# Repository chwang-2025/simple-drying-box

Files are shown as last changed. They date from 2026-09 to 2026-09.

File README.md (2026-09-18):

# 简易干燥盒

基于 STC8H1K17T 的小型加热干燥盒项目，包含外壳模型、电路资料和固件。项目仍处于原型验证阶段；现有固件针对**第一版实装 PCB**，请先核对接线并完成无负载测试，再连接加热片。

## 项目内容

| 路径 | 内容 |
| --- | --- |
| [`firmware/oled_test/`](firmware/oled_test/) | PlatformIO 固件、烧录辅助脚本和第一版 PCB 接线说明 |
| [`原理图/`](原理图/) | 原理图 PDF 与物料清单 |
| [`PCB/`](PCB/) | PCB 截图 |
| `*.SLDPRT`、`*.SLDASM`、`*.step` | 结构设计与 PCB 三维文件 |
| [`干燥盒子项目_简易.md`](干燥盒子项目_简易.md) | 原始功能规划，部分内容尚未在现有版本实现 |

## 当前固件

- OLED 显示温度和运行状态，按键设定目标温度（30～80 ℃）及倒计时（5～180 分钟）。
- 加热输出采用 5 秒周期的时间比例控制；温度远低于设定值时全功率输出，接近设定值时使用待实测整定的 PID 参数。
- NTC 读数异常、温度达到 85 ℃、倒计时结束或人工停止时关闭加热；故障锁定后需检查硬件并重新上电。
- **这一版不接风扇。**原风扇接口 H2 改作加热输出，H3 不可接加热片。第一版 PCB 的原理图库引脚映射与实装芯片不一致，详见[固件接线和验收说明](firmware/oled_test/README.md)。

## 编译

安装 PlatformIO 后，在 `firmware/oled_test` 目录执行：

```sh
platformio run
```

生成文件位于 `.pio/build/oled_test/firmware.hex`。编译通过仅说明固件可构建，不代表温控精度或实物安全已验证。

## 使用前检查

1. 核对实装芯片型号、H2 接口极性、加热片额定电压和功率，以及电源、驱动器件和 PCB 走线的承载能力。
2. **先断开加热片**，按[固件说明](firmware/oled_test/README.md)验证待机、运行、停止和 NTC 故障状态下的驱动电压。
3. 为加热片设置独立于单片机的软件之外的温度保护，并检查外壳材料的耐热性。
4. 记录实际升温和超调曲线，再整定 PID 参数；不要将当前参数视为已经验证的恒温性能。

## 说明

原始功能规划提到风扇排湿等目标；当前第一版 PCB 固件的实际接线和功能以 [`firmware/oled_test/README.md`](firmware/oled_test/README.md) 为准。仓库不包含本地编译结果、Python 环境和临时文件。

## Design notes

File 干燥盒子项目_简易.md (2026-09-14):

# 简易干燥盒 —— 功能总结报告

## 一、项目定位

便携式实验室**恒温干燥盒（简易版）**，用于小体积样品（如电子元件、试剂、小型器件）的加热干燥与防潮保存。相比智能版（TEC 能量回收 + 内胆识别），本版砍掉复杂功能，主打**低成本（¥15–20）、结构简单、易维护**。

## 二、核心功能

| 功能模块 | 实现方式 | 说明 |
|---|---|---|
| **恒温加热** | PTC 加热片 + PWM 控制 | 5V/5W PTC 加热片，通过 PWM 调节加热功率实现温度闭环 |
| **温度监测** | NTC 热敏电阻（100k B=3950）+ ADC | 分压采样，实时读取腔内温度，作为控温反馈 |
| **气流循环/排湿** | 5V 微型风扇 + PWM | 加速腔内空气流动，带走湿气、均匀温度 |
| **状态显示** | 0.96" OLED（SSD1306 I²C） | 显示当前温度、目标温度、工作模式 |
| **用户交互** | 3 个轻触按键 | UP / MODE / DOWN，调温与模式切换 |
| **声光提示** | 无源蜂鸣器 + 红色 LED | 按键反馈、到温/超温报警、工作状态指示 |
| **供电** | USB-C 5V 输入 | AMS1117 转 3.3V 供 MCU，TVS+肖特基防反接/防浪涌 |
| **调试通信** | CH340N（USB 转 UART） | 串口烧录与上位机调试 |

## 三、控制逻辑（预期）

1. 用户通过按键设定**目标温度**（如 40°C / 50°C / 60°C）
2. MCU 读取 NTC 温度 → 与目标比较 → 输出 PWM 驱动 PTC 加热
3. 温度接近目标时降低占空比，实现 PID 或分段温控
4. 超温时停止加热并蜂鸣报警；风扇按需运行辅助排湿/降温
5. OLED 实时刷新温度与状态，LED 指示工作/报警

## 四、硬件架构概览

- **主控**：STC8H1K17T（SOP-20，8051 内核，自带 PWM/ADC）
- **电源链**：USB-C → SS34 反接保护 → TVS 浪涌 → AMS1117-3.3
- **驱动**：AO3400 N-MOSFET ×2（PTC、风扇）+ S8050（蜂鸣器）
- **板框**：60mm × 45mm，立创EDA

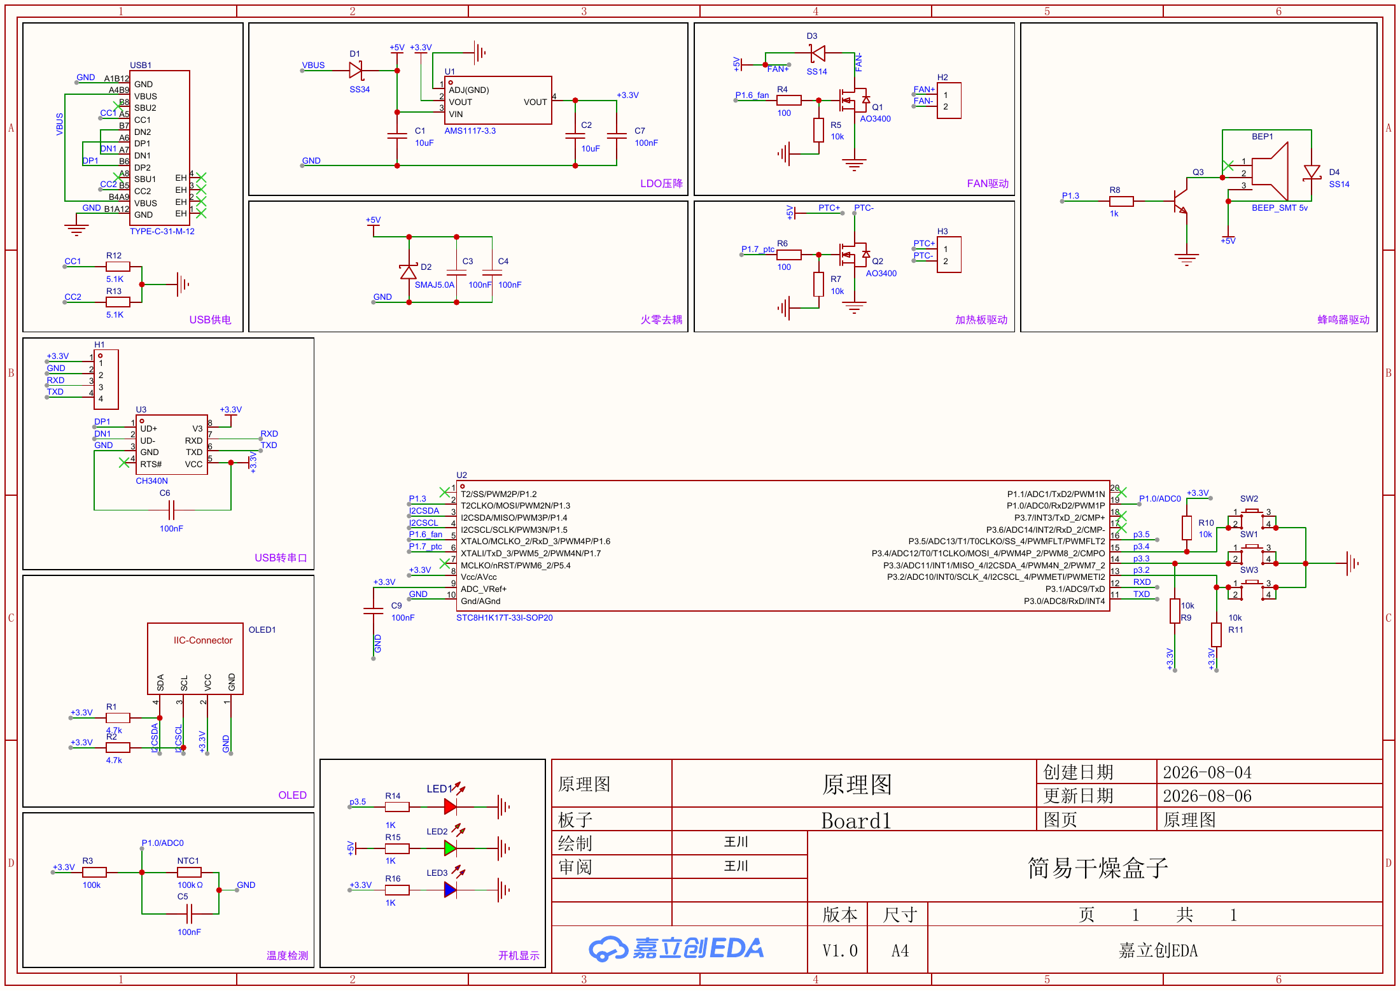
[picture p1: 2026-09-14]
schematic-review.png

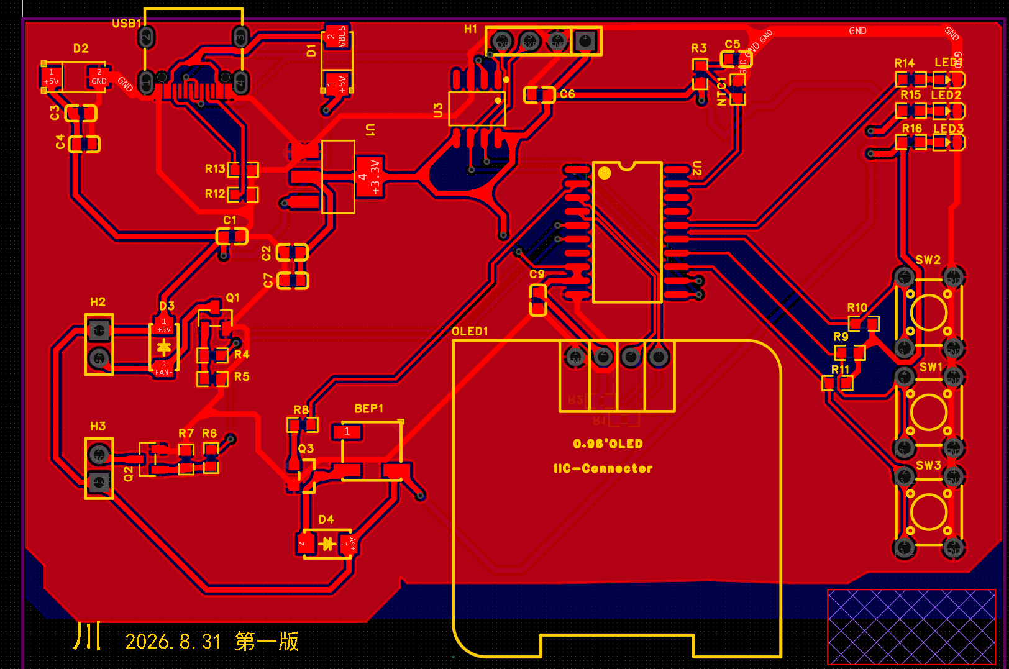
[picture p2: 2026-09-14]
PCB/Screenshot 2026-09-11 123319.png

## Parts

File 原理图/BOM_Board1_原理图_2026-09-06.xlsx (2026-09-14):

No. | Comment | Designator | Footprint | Value | Manufacturer Part | Manufacturer | Supplier Part | Supplier | Category | Device | 匹配状态 | 对方 BOM 对应位号 | 匹配依据
4 | SS34 | D1 | SMA_L4.3-W2.6-LS5.2-RD | 16 | SS34 | MDD(辰达半导体) | C8678 | LCSC | 二极管:肖特基二极管 | SS34_C8678
5 | SMAJ5.0A | D2 | SMA_L4.4-W2.6-LS5.0-RD | 16 | SMAJ5.0A | FMS(美丽微) | C143135 | LCSC | 三极管/MOS管/晶体管:静电和浪涌保护(TVS/ESD) | SMAJ5.0A
6 | SS14 | D3,D4 | SMA_L4.2-W2.6-LS5.0-RD_1 | 16 | SS14 | MDD(辰达半导体) | C2480 | LCSC | 二极管:肖特基二极管 | SS14_C2480
14 | AO3400 | Q1,Q2 | SOT-23-3_L2.9-W1.3-P1.90-LS2.4-BL-2 | 16 | AO3400 | 16 | C9900013365 | LCSC | 16 | AO3400
15 | S8050_SOT_NPN | Q3 | S8050_SOT-23 | 16 | 16 | 16 | 16 | 16 | 16 | S8050_SOT_NPN
23 | Key_TH_6x6x6 | SW1,SW2,SW3 | SW-TH_4P-L6.0-W6.0-P4.50-LS6.5 | 16 | 16 | 16 | 16 | 16 | 按键/开关:轻触开关 | Key_TH_6x6x6
24 | AMS1117-3.3 | U1 | SOT-223-3_L6.5-W3.4-P2.30-LS7.0-BR | 16 | AMS1117-3.3 | YONGYUTAI(永裕泰) | C2891839 | LCSC | 电源管理:线性稳压器(LDO) | AMS1117-3.3
25 | STC8H1K17T-33I-SOP20 | U2 | SOP-20_L12.7-W7.5-P1.27-LS10.3-BL | 16 | STC8H1K17T-33I-SOP20 | STC | C20416480 | LCSC | 单片机/微控制器:单片机(MCU/MPU/SOC) | STC8H1K17T-33I-SOP20
26 | CH340N | U3 | SOP-8_L4.9-W3.9-P1.27-LS6.0-BL | 16 | CH340N | WCH(南京沁恒) | C2977777 | LCSC | 通信接口芯片:USB转换芯片 | CH340N
16

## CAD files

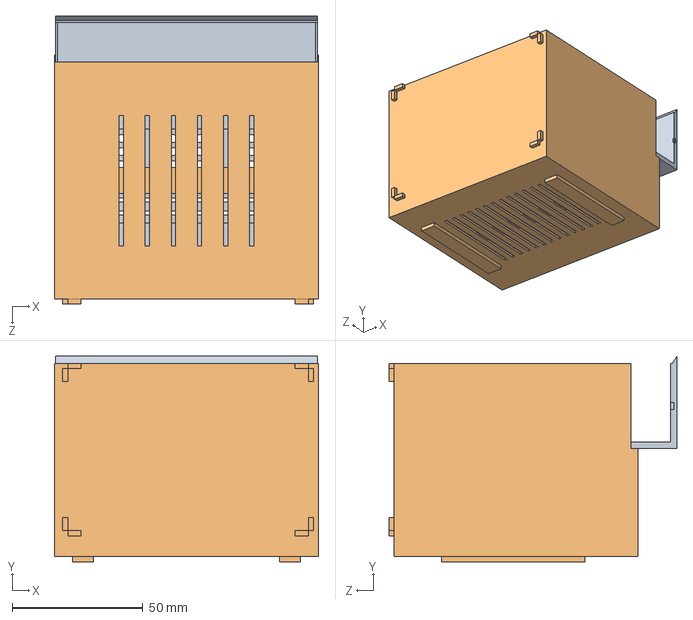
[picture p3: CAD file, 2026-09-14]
干燥盒子项目.SLDASM
101.2 x 78.8 x 110.2 mm
盒子
抽屉托盘

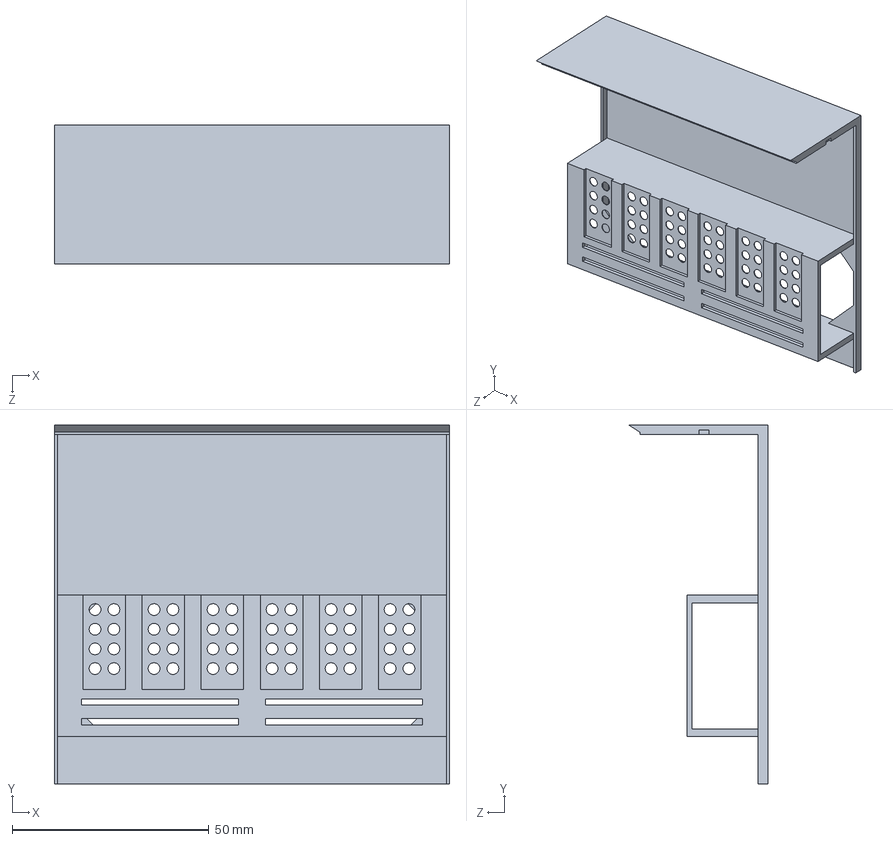
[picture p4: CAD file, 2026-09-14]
抽屉托盘.SLDPRT
100.4 x 91.2 x 35.4 mm

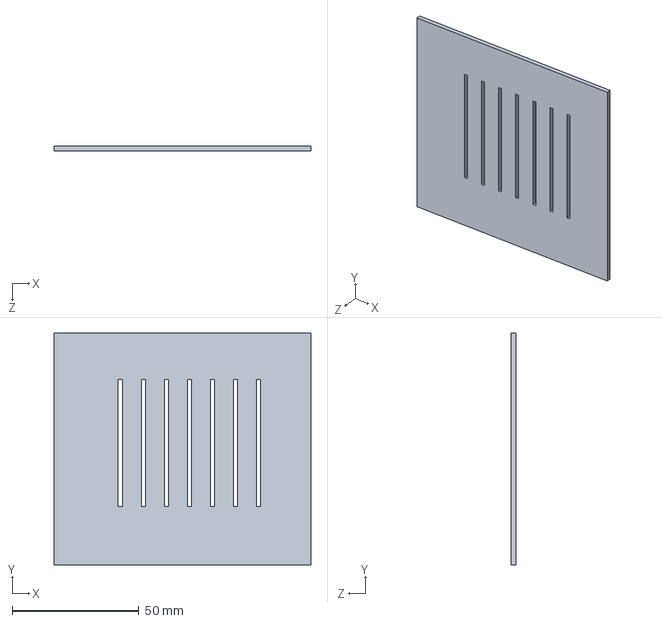
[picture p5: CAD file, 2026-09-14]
托盘.SLDPRT
101.2 x 91.2 x 2.00 mm

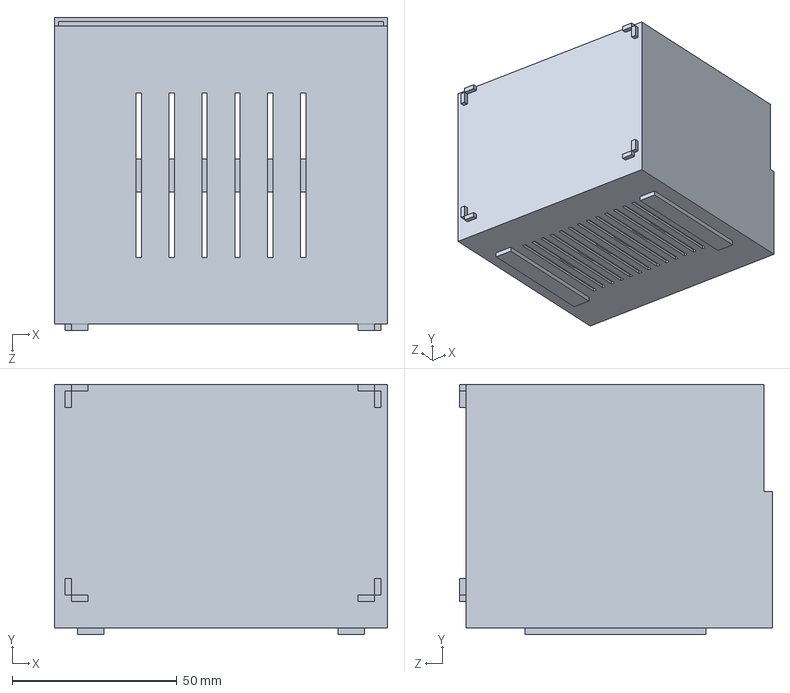
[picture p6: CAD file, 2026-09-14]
盒子.SLDPRT
101.2 x 76.0 x 95.2 mm

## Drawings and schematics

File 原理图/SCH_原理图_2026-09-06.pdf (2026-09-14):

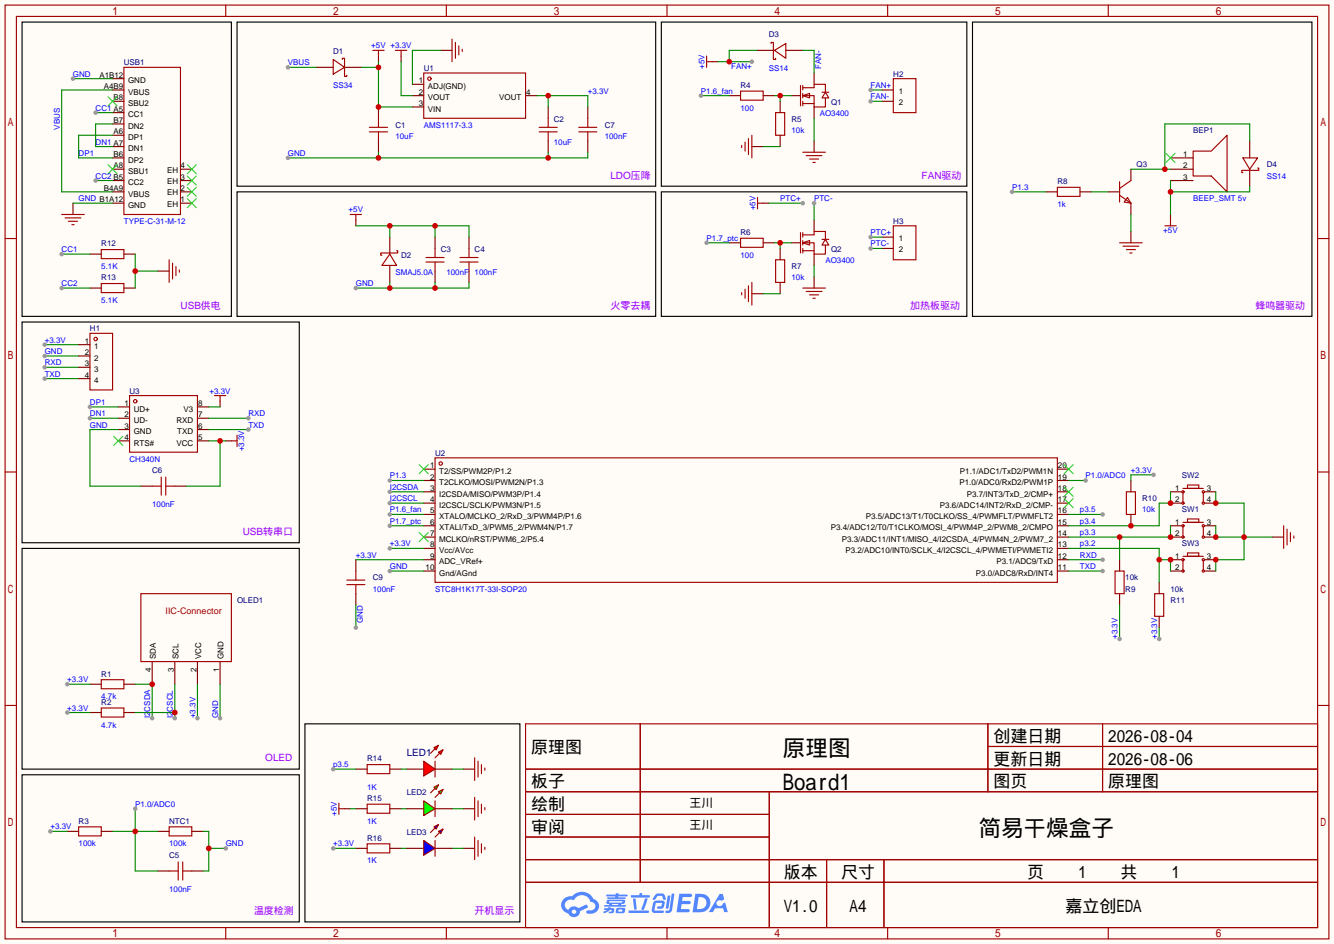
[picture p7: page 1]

原理图 | 原理图 | 创建日期 | 2026-08-04

更新日期 | 2026-08-06

板子 | Board1 | 图页 | 原理图
绘制 | 王川 | 简易干燥盒子
审阅 | 王川

V1.0 | A4 | 嘉立创EDA

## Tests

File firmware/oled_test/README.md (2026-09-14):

# 干燥盒固件：H2 改作加热输出

本版适用于实装 `STC8H1K17T-33I-SOP20` 的第一版 PCB。原理图库的左侧引脚映射与实装芯片不一致，必须以实装芯片和实测线路为准。

## 关键接线

- OLED：U2 物理 3/4 脚，实际为 P1.6/P1.7，分别驱动 SDA/SCL。
- 蜂鸣器：U2 物理 2 脚，实际为 P1.5，经 Q3 驱动。
- **加热片只可接 H2（原风扇接口）**：U2 物理 5 脚，实际为 P1.3，经 R4、Q1 驱动。
- **H3 不可接加热片**：其 Q2 控制网络接 U2 物理 6 脚，该脚在实装型号上是 TCap，不是 GPIO。
- 不再连接风扇；也不要同时在 H2 接风扇和加热片。

本文件中的引脚结论源于实装芯片型号、原理图、PCB 网络和 OLED 引脚电压实验。PCB 上 `P1.6_fan`、`P1.7_ptc` 是旧原理图库产生的**网络名称**，不是实装芯片相应物理脚的功能。

## 当前控制方式

- 上电及待机时加热输出关闭。长按 SW1 启动设定的倒计时。
- 低于设定温度 5℃ 及以上时，H2 加热输出 **100% 导通**；接近设定温度时，按固定点 PID 计算 0～100% 的加热占空比。OLED 显示 `HEAT xxx%`（平均输出比例，不是瞬时开关状态）。
- 采用 5 秒周期的时间比例控制，而不是高频 PWM；每秒更新一次 PID。超过设定温度 2℃ 时强制停止加热。PID 系数只是保守起始值，必须记录实测升温/超调曲线后再整定，不能保证第一次就精确恒温。
- NTC 首次异常读数即关闭输出；运行中发生异常或温度达到 85℃ 时锁定 `FAULT` 并报警，需检查硬件后重新上电。
- 倒计时到 0 或人工停止时立即关闭输出。设置温度 30～80℃，时间 5～180 分钟。
- OLED 左侧竖线修正：上电清除控制器全部 132 列显存。

## 接负载前的必要验收

1. 加热片先保持断开，仅用 USB 为板供电并烧录固件。
2. 待机时测 Q1 栅极对地应接近 0V；启动且当前温度明显低于设定温度时应接近 3.3V；停止或断开 NTC 后应回到 0V。
3. 确认 H2 两脚的极性和负载连接，且加热片的**实际**额定电压、电流/功率与 Q1、D1、H2、PCB 走线以及 5V 电源的额定能力相容。项目最初方案写的是 5V/5W，但它不能替代实物铭牌核对。
4. 加热片应另有独立于单片机的温度保护（例如适当温度的热熔断器），并远离不耐热的外壳材料。仅靠软件故障保护不足以防范 MCU 死机或 MOSFET 短路。

## 充电宝供电注意

待机约 30 秒后整板熄灭、Type-C 电压跌到约 1.6～1.7V，而加热时正常，符合充电宝低负载自动断电的表现，但需用稳定 5V 电源交叉验证。PID 恒温时也可能出现长时间低占空比或 0% 输出，充电宝仍可能自动断电；固件**不会为保活而强行加热**。需要可靠的长时间运行时，选不会自动断电的 5V 电源或明确支持低电流模式的移动电源。

编译：`platformio run`。输出：`.pio/build/oled_test/firmware.hex`。编译成功不代表实物功能和热安全已验证。

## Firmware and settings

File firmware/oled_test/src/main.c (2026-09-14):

/*
 * STC8H1K17T drying-box heater/UI build.
 * IMPORTANT: this firmware repurposes the ORIGINAL FAN OUTPUT H2 as the
 * heater output. H3 is wired to U2 physical pin 6 (TCap), not a GPIO;
 * never connect the heater to H3 on this PCB revision.
 */
__sfr __at(0x89) TMOD; __sfr __at(0x8a) TL0; __sfr __at(0x8c) TH0;
__sfr __at(0x8e) AUXR; __sfr __at(0x90) P1; __sfr __at(0x91) P1M1;
__sfr __at(0x92) P1M0; __sfr __at(0xb0) P3; __sfr __at(0xb1) P3M1;
__sfr __at(0xb2) P3M0; __sfr __at(0xba) P_SW2;
__sfr __at(0xbc) ADC_CONTR; __sfr __at(0xbd) ADC_RES;
__sfr __at(0xbe) ADC_RESL; __sfr __at(0xde) ADCCFG;
__xdata __at(0xfea8) unsigned char ADCTIM;

/* PCB OLED pins are U2 physical 3/4 = P1.6/P1.7 on the fitted T variant. */
__sbit __at(0x96) SDA; __sbit __at(0x97) SCL;
__sbit __at(0x95) BUZZER;   /* U2 physical pin 2 = P1.5, drives Q3 */
__sbit __at(0x93) HEATER;   /* U2 physical pin 5 = P1.3, drives Q1/H2 */
__sbit __at(0xb2) KEY_MINUS; /* SW3 */
__sbit __at(0xb3) KEY_MODE;  /* SW1 */
__sbit __at(0xb4) KEY_PLUS;  /* SW2 */
__sbit __at(0xb5) LED;
__sbit __at(0x8c) TR0; __sbit __at(0xa9) ET0; __sbit __at(0xaf) EA;

static volatile unsigned char tick5, second_event;
static unsigned char address, mode, set_temp = 50, set_minutes = 30;
static unsigned char beep_ticks, alarm_edges, alarm_tick;
static unsigned int control_temp10 = 0xffff;
static unsigned char fault_latched;
static unsigned long remaining;
static unsigned int temp10 = 0xffff;
static unsigned char invalid_temp_count;
/* 5 s time-proportion heater output: 1000 slots of 5 ms. */
static volatile unsigned int heater_duty, heater_phase;
static volatile unsigned char heater_enabled;
static signed int pid_integral8, pid_slope4;
static unsigned int pid_last_temp;

/* ASCII 0x20..0x5a, 5x7 font. */
static const __code unsigned char font[] = {
0,0,0,0,0, 0,0,0x5f,0,0, 0,7,0,7,0, 0x14,0x7f,0x14,0x7f,0x14,
0x24,0x2a,0x7f,0x2a,0x12, 0x23,0x13,8,0x64,0x62, 0x36,0x49,0x55,0x22,0x50,
0,5,3,0,0, 0,0x1c,0x22,0x41,0, 0,0x41,0x22,0x1c,0,
0x14,8,0x3e,8,0x14, 8,8,0x3e,8,8, 0,0x50,0x30,0,0,
8,8,8,8,8, 0,0x60,0x60,0,0, 0x20,0x10,8,4,2,
0x3e,0x51,0x49,0x45,0x3e, 0,0x42,0x7f,0x40,0,
0x42,0x61,0x51,0x49,0x46, 0x21,0x41,0x45,0x4b,0x31,
0x18,0x14,0x12,0x7f,0x10, 0x27,0x45,0x45,0x45,0x39,
0x3c,0x4a,0x49,0x49,0x30, 1,0x71,9,5,3,
0x36,0x49,0x49,0x49,0x36, 6,0x49,0x49,0x29,0x1e,
0,0x36,0x36,0,0, 0,0x56,0x36,0,0, 8,0x14,0x22,0x41,0,
0x14,0x14,0x14,0x14,0x14, 0,0x41,0x22,0x14,8, 2,1,0x51,9,6,
0x32,0x49,0x79,0x41,0x3e, 0x7e,0x11,0x11,0x11,0x7e,
0x7f,0x49,0x49,0x49,0x36, 0x3e,0x41,0x41,0x41,0x22,
0x7f,0x41,0x41,0x22,0x1c, 0x7f,0x49,0x49,0x49,0x41,
0x7f,9,9,9,1, 0x3e,0x41,0x49,0x49,0x7a, 0x7f,8,8,8,0x7f,
0,0x41,0x7f,0x41,0, 0x20,0x40,0x41,0x3f,1,
0x7f,8,0x14,0x22,0x41, 0x7f,0x40,0x40,0x40,0x40,
0x7f,2,0x0c,2,0x7f, 0x7f,4,8,0x10,0x7f, 0x3e,0x41,0x41,0x41,0x3e,
0x7f,9,9,9,6, 0x3e,0x41,0x51,0x21,0x5e, 0x7f,9,0x19,0x29,0x46,
0x46,0x49,0x49,0x49,0x31, 1,1,0x7f,1,1, 0x3f,0x40,0x40,0x40,0x3f,
0x1f,0x20,0x40,0x20,0x1f, 0x3f,0x40,0x38,0x40,0x3f,
0x63,0x14,8,0x14,0x63, 7,8,0x70,8,7, 0x61,0x51,0x49,0x45,0x43
};

/* 100k/B3950 NTC with 100k pull-up: ADC at 0,5,...105 C. */
static const __code unsigned int ntc[] = {
3156,2955,2738,2510,2278,2048,1825,1614,1419,1241,1081,
940,815,707,613,532,462,401,350,305,267,234};

unsigned char __sdcc_external_startup(void)
{
    P1 = 0xc7;                  /* safe latches, OLED released */
    P1M1 &= (unsigned char)~0xc0; P1M0 &= (unsigned char)~0xc0;
    P3 &= 0xdf; P3M1 &= 0xdf; P3M0 |= 0x20;
    return 0;
}

static void delay_i2c(void)
{ volatile unsigned char n; for (n = 0; n < 40; ++n) { } }

static void start(void)
{ SDA=1; SCL=1; delay_i2c(); SDA=0; delay_i2c(); SCL=0; }
static void stop(void)
{ SCL=0; SDA=0; delay_i2c(); SCL=1; delay_i2c(); SDA=1; delay_i2c(); }

static unsigned char send(unsigned char v)
{
    unsigned char i, ack;
    for (i=0; i<8; ++i) {
        SDA=((v&0x80)!=0); delay_i2c(); SCL=1; delay_i2c(); SCL=0; v<<=1;
    }
    SDA=1; delay_i2c(); SCL=1; delay_i2c(); ack=!SDA; SCL=0;
    return ack;
}

static unsigned char probe(unsigned char a)
{ unsigned char ok; start(); ok=send(a); stop(); return ok; }

static void command(unsigned char v)
{ start(); send(address); send(0); send(v); stop(); }

static void set_pos(unsigned char page, unsigned char col)
{
    unsigned char c=col+2;
    command(0xb0|page); command(c&15); command(0x10|(c>>4));
}

static void set_raw_pos(unsigned char page, unsigned char col)
{
    command(0xb0|page); command(col&15); command(0x10|(col>>4));
}

static void clear(void)
{
    unsigned char p,x;
    for (p=0;p<8;++p) {
        /* Clear all 132 controller columns, including the two left-edge
         * columns omitted by the usual SH1106 visible-area +2 offset. */
        set_raw_pos(p,0); start(); send(address); send(0x40);
        for (x=0;x<132;++x) send(0); stop();
    }
}

static void line(unsigned char page, const char *s)
{
    unsigned char x=0,i,ch; unsigned int k;
    set_pos(page,0); start(); send(address); send(0x40);
    while (*s && x<126) {
        ch=(unsigned char)*s++; if(ch<0x20||ch>0x5a)ch=' ';
        k=(unsigned int)(ch-0x20)*5;
        for(i=0;i<5&&x<128;++i,++x)send(font[k+i]);
        if(x<128){send(0);++x;}
    }
    while(x++<128)send(0); stop();
}

static void oled_init(void)
{
    static const __code unsigned char seq[]={
    0xae,0xd5,0x80,0xa8,0x3f,0xd3,0,0x40,0x20,2,0xa1,0xc8,0xda,0x12,
    0x81,0x7f,0xd9,0xf1,0xdb,0x40,0xa4,0xa6,0x8d,0x14,0xad,0x8b,0xaf};
    unsigned char i; for(i=0;i<sizeof(seq);++i)command(seq[i]);
    command(0xa4); clear();
}

static void timer_init(void)
{
    AUXR|=0x80; TMOD=(TMOD&0xf0)|1; TH0=0x28; TL0=0;
    ET0=1; EA=1; TR0=1;
}

void timer0_isr(void) __interrupt(1)
{
    static unsigned char n;
    TH0=0x28; TL0=0;
    if(++heater_phase>=1000u)heater_phase=0;
    HEATER=(heater_enabled && heater_phase<heater_duty);
    if(tick5<250)++tick5; /* Preserve elapsed ticks while OLED is drawing. */
    if(++n>=200){n=0;if(second_event<250)++second_event;}
}

static void adc_init(void)
{
    P1M1|=1; P1M0&=(unsigned char)~1;
    P_SW2|=0x80; ADCTIM=0x3f; P_SW2&=0x7f;
    ADCCFG=0x2f; ADC_CONTR=0x80;
}

static unsigned int adc_read(void)
{
    unsigned int timeout=60000;
    ADC_CONTR=0xc0;
    while(!(ADC_CONTR&0x20)&&--timeout){ }
    ADC_CONTR&=(unsigned char)~0x20;
    return ((unsigned int)ADC_RES<<8)|ADC_RESL;
}

static unsigned int read_temp(void)
{
    unsigned long sum=0;
    unsigned int a, sample, minimum=0xffff, maximum=0;
    unsigned char i;

    /* Discard one conversion after channel selection, then use a trimmed mean. */
    (void)adc_read();
    for(i=0;i<16;++i){
        sample=adc_read();
        sum+=sample;
        if(sample<minimum)minimum=sample;
        if(sample>maximum)maximum=sample;
    }
    a=(unsigned int)((sum-minimum-maximum+7ul)/14ul);
    if(a>3500||a<210)return 0xffff; /* NTC missing/open */
    if(a>=ntc[0])return 0;
    for(i=0;i<21;++i)if(a>=ntc[i+1])
        return (unsigned int)i*50u+(unsigned int)
        ((unsigned long)(ntc[i]-a)*50u/(ntc[i]-ntc[i+1]));
    return 1050;
}

static void update_temperature(void)
{
    unsigned int raw=read_temp();

    if(raw==0xffff){
        control_temp10=0xffff; /* Turn heater off on the first bad reading. */
        /* Do not blank the display for a single noisy/out-of-range sample. */
        if(invalid_temp_count<3)++invalid_temp_count;
        if(invalid_temp_count>=3)temp10=0xffff;
        return;
    }
    invalid_temp_count=0;

    /* Empirical board/sensor calibration: displayed temperature was +0.5 C. */
    raw=(raw>=5)?(raw-5):0;
    control_temp10=raw; /* Use unsmoothed data for the safety cutoff. */

    if(temp10==0xffff)temp10=raw;
    else {
        /* EMA alpha=1/8: suppress ADC noise and fast visual jumping. */
        temp10=(unsigned int)(((unsigned long)temp10*7ul+raw+4ul)/8ul);
    }
}

static void blank(char *s)
{ unsigned char i; for(i=0;i<21;++i)s[i]=' '; s[21]=0; }
static void text(char *s,unsigned char p,const char *v)
{ while(*v&&p<21)s[p++]=*v++; }

static void draw(void)
{
    char s[22]; unsigned int w,m,power; unsigned long shown; unsigned char sec;
    blank(s);text(s,0,"TEMP:");
    if(temp10==0xffff)text(s,6,"--.-C");
    else {w=temp10/10;s[6]=(w>=100)?'0'+(w/100)%10:' ';s[7]='0'+(w/10)%10;
          s[8]='0'+w%10;s[9]='.';s[10]='0'+temp10%10;s[11]='C';} line(0,s);
    blank(s);text(s,0,"SET :");s[6]='0'+set_temp/10;s[7]='0'+set_temp%10;s[8]='C';line(2,s);
    shown=(mode==3||mode==4)?remaining:(unsigned long)set_minutes*60ul;
    m=(unsigned int)(shown/60ul);sec=(unsigned char)(shown%60ul);
    blank(s);text(s,0,"TIME:");s[5]='0'+(m/100)%10;s[6]='0'+(m/10)%10;
    s[7]='0'+m%10;s[8]=':';s[9]='0'+sec/10;s[10]='0'+sec%10;line(4,s);
    blank(s);text(s,0,"STATE:");
    if(mode==0)text(s,6,"READY");else if(mode==1)text(s,6,"SET TEMP");
    else if(mode==2)text(s,6,"SET TIME");
    else if(mode==3){
        text(s,6,"HEAT ");
        EA=0;power=heater_duty;EA=1;
        power=(power+5u)/10u;
        s[11]='0'+(power/100u)%10u;
        s[12]='0'+(power/10u)%10u;
        s[13]='0'+power%10u;s[14]='%';
    }
    else if(mode==4)text(s,6,"DONE");
    else text(s,6,"FAULT"); line(6,s);
}

static void beep_short(void)
{
    alarm_edges=0; alarm_tick=0;
    BUZZER=1; beep_ticks=20; /* 100 ms */
}

static void alarm_three_beeps(void)
{
    beep_ticks=0; alarm_tick=0;
    BUZZER=1; alarm_edges=5; /* Three 200 ms tones. */
}

static void buzzer_service(void)
{
    if(beep_ticks){
        if(!--beep_ticks)BUZZER=0;
    } else if(alarm_edges && ++alarm_tick>=40){
        alarm_tick=0; BUZZER=!BUZZER;
        if(!--alarm_edges)BUZZER=0;
    }
}

static void heater_off(void)
{
    heater_enabled=0;HEATER=0;
}

/* Conservative fixed-point PID, updated once per second. Raw temperature is
 * used for control to avoid the display filter's ~8 s thermal lag. */
static void pid_update(void)
{
    signed int error, rise, output;
    unsigned int duty;

    if(control_temp10==0xffff)return;
    error=(signed int)((unsigned int)set_temp*10u)-(signed int)control_temp10;
    rise=(signed int)control_temp10-(signed int)pid_last_temp;
    pid_last_temp=control_temp10;
    if(rise>20)rise=20;else if(rise< -20)rise= -20;
    pid_slope4=(signed int)((pid_slope4*3+rise*4)/4);

    if(error>=50){ /* More than 5 C below target: warm up at full power. */
        pid_integral8=0;duty=1000;
    } else if(error<= -20){ /* More than 2 C above target: no heating. */
        pid_integral8=0;duty=0;
    } else {
        /* P: 14 permille/0.1 C; I: 1/8 permille/0.1 C/s;
         * D: 8 permille per quarter-degree/s slope unit. */
        output=250+error*14+pid_integral8/8-pid_slope4*8;
        if(error<=20 && output>0 && output<1000){
            pid_integral8+=error;
            if(pid_integral8>4000)pid_integral8=4000;
            if(pid_integral8< -4000)pid_integral8= -4000;
            output=250+error*14+pid_integral8/8-pid_slope4*8;
        }
        if(output<0)duty=0;
        else if(output>1000)duty=1000;
        else duty=(unsigned int)output;
    }
    EA=0;heater_duty=duty;EA=1;
}

static void heater_service(void)
{
    if(mode!=3 || fault_latched){heater_off();return;}
    if(control_temp10==0xffff || control_temp10>=850u){
        heater_off();fault_latched=1;mode=5;alarm_three_beeps();return;
    }

    if(!heater_enabled){
        pid_integral8=0;pid_slope4=0;pid_last_temp=control_temp10;
        pid_update();
        EA=0;heater_phase=0;heater_enabled=1;EA=1;
    }
}

static void adjust(signed char d)
{
    if(mode==1){if(d>0&&set_temp<80)++set_temp;if(d<0&&set_temp>30)--set_temp;}
    if(mode==2){if(d>0&&set_minutes<=175)set_minutes+=5;
                if(d<0&&set_minutes>5)set_minutes-=5;}
}

static unsigned char keys(void)
{
    static unsigned char cm,cp,cn,long_done; unsigned char changed=0;
    if(!KEY_MODE){if(cm<250)++cm;if(cm>=200&&!long_done){long_done=1;
        if(mode==3)mode=0;
        else if(!fault_latched && control_temp10!=0xffff){
            remaining=(unsigned long)set_minutes*60ul;mode=3;
        }
        beep_short();changed=1;}}
    else {if(cm>=4&&!long_done){if(mode==0||mode==4)mode=1;else if(mode==1)mode=2;
          else mode=0;changed=1;}cm=0;long_done=0;}
    if(!KEY_PLUS){if(cp<250)++cp;if(cp==4||(cp>100&&!(cp%20))){adjust(1);changed=1;}}
    else cp=0;
    if(!KEY_MINUS){if(cn<250)++cn;if(cn==4||(cn>100&&!(cn%20))){adjust(-1);changed=1;}}
    else cn=0;
    return changed;
}

void main(void)
{
    unsigned char redraw=1; volatile unsigned int d;
    P1M1|=0xc0;P1M0|=0xc0;P1|=0xc0;
    P1M1&=(unsigned char)~0x08;P1M0|=0x08;HEATER=0;
    P1M1&=(unsigned char)~0x20;P1M0|=0x20;BUZZER=0;
    P3M1|=0x1c;P3M0&=(unsigned char)~0x1c;P3|=0x1c;LED=0;
    for(d=0;d<60000;++d){ }
    if(probe(0x78))address=0x78;else if(probe(0x7a))address=0x7a;
    else for(;;){LED=!LED;for(d=0;d<60000;++d){ }}
    oled_init();adc_init();update_temperature();timer_init();LED=1;beep_short();
    for(;;){
        if(!tick5)continue;
        EA=0;--tick5;EA=1;
        buzzer_service();if(keys())redraw=1;
        heater_service(); /* A button press changes the output without delay. */
        if(second_event){
            EA=0;--second_event;EA=1;
            update_temperature();
            if(mode==3&&remaining){--remaining;
                if(!remaining){mode=4;heater_off();alarm_three_beeps();}
                else if(control_temp10!=0xffff && control_temp10<850u)
                    pid_update();}
            redraw=1;
        }
        heater_service(); /* Also react immediately to a new NTC reading. */
        if(redraw){redraw=0;draw();}
    }
}

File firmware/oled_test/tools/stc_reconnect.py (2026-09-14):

"""Reconnect-aware launcher for STC ISP on boards sharing USB power with CH340."""
import argparse
import subprocess
import sys
import time
from pathlib import Path

import serial
from serial.tools import list_ports


def port_present(name: str) -> bool:
    return any(p.device.upper() == name.upper() for p in list_ports.comports())


def wait_for(name: str, present: bool) -> None:
    while port_present(name) != present:
        time.sleep(0.05)


def wait_until_openable(name: str) -> None:
    """A newly enumerated CH340 can be listed before Windows accepts I/O."""
    while True:
        try:
            with serial.Serial(name, 2400, timeout=0.05, write_timeout=0.05):
                pass
            return
        except (serial.SerialException, PermissionError, OSError):
            time.sleep(0.05)


def main() -> int:
    parser = argparse.ArgumentParser()
    parser.add_argument("--port", default="COM8")
    parser.add_argument("--flash", type=Path)
    args = parser.parse_args()

    project = Path(__file__).resolve().parents[1]
    stcgal = project / ".tools" / "stcgal" / "Scripts" / "stcgal.exe"
    if not stcgal.exists():
        print(f"找不到烧录工具：{stcgal}", flush=True)
        return 2

    print(f"目标串口：{args.port}", flush=True)
    if port_present(args.port):
        print("第1步：现在拔掉开发板USB线。", flush=True)
        wait_for(args.port, False)
    print("已检测到串口断开。", flush=True)
    print("第2步：现在重新插入开发板USB线；程序会自动打开串口。", flush=True)
    wait_for(args.port, True)
    print("已检测到串口，正在等待Windows驱动允许读写……", flush=True)
    wait_until_openable(args.port)
    time.sleep(0.05)
    print("串口已可读写，正在连接STC启动程序……", flush=True)

    # STC8H1Kxx uses the newer STC8G-family ISP framing in stcgal.
    command = [str(stcgal), "-P", "stc8g", "-p", args.port]
    if args.flash:
        image = args.flash.resolve()
        if not image.exists():
            print(f"找不到固件：{image}", flush=True)
            return 2
        command += ["-t", "11059", str(image)]
    return subprocess.call(command)


if __name__ == "__main__":
    sys.exit(main())

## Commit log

2026-09-14 添加简易干燥盒项目资料与中文说明
    [BOM_Board1_原理图_2026-09-06.xlsx, 干燥盒子项目.SLDASM, 托盘.SLDPRT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]
2026-09-18 Delete 盒子.3mf
    正在整合
    [盒子.3mf]
